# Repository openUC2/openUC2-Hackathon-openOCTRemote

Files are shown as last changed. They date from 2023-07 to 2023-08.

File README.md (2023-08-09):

# Hackathon: openOCT - Full-field Incoherent Interferemeter for better optical sectioning with remote control capabilities

Welcome to the openOCT Hackathon! In this hackathon, we will be addressing the crucial need for an open-source optical coherence tomography system that can help students learning more about setting up a low-coherence interferemoter. To keep the budget low, we aim for a full-field time domain OCT using an SLD (super luminescent diode) - alternatively one could also try an LED to lower the costs even more

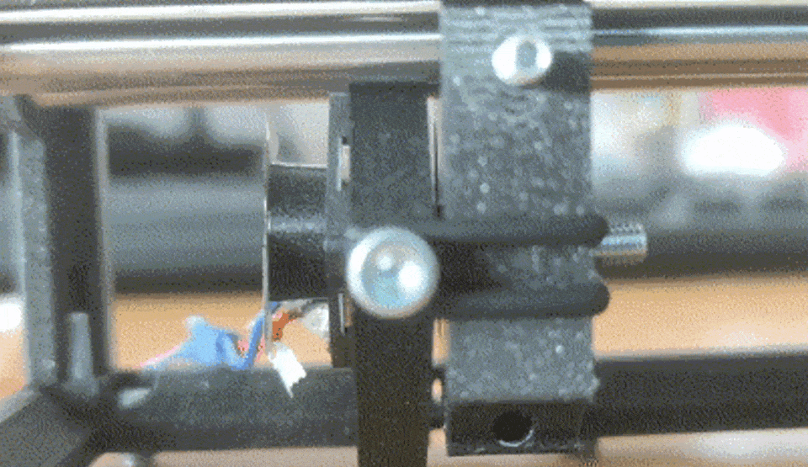
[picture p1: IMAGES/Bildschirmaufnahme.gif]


## Motivation

Optical coherence tomography (OCT) is a non-invasive optical method that allows for deep imaging within tissues. It is primarily based on a Michelson-type interferometer, where the light source is generated by a low-coherence light source, such as a superluminescent diode (SLD). The coherence volume, which represents the volume where constructive interference is observed, is inversely proportional to the spectral bandwidth of the light source.

However, adjusting a Michelson interferometer is not a straightforward process, as the lengths of the reference and sample arms need to match by approximately 10 µm. To address this challenge, a common-path-type full-field OCT is employed, where both arms are illuminated by an SLD, and the sample or mirror is imaged using a long-working distance objective or a simple lens. This alignment method simplifies the process since the "sample" or mirror is brought into focus, ensuring that the path lengths are nearly equal.

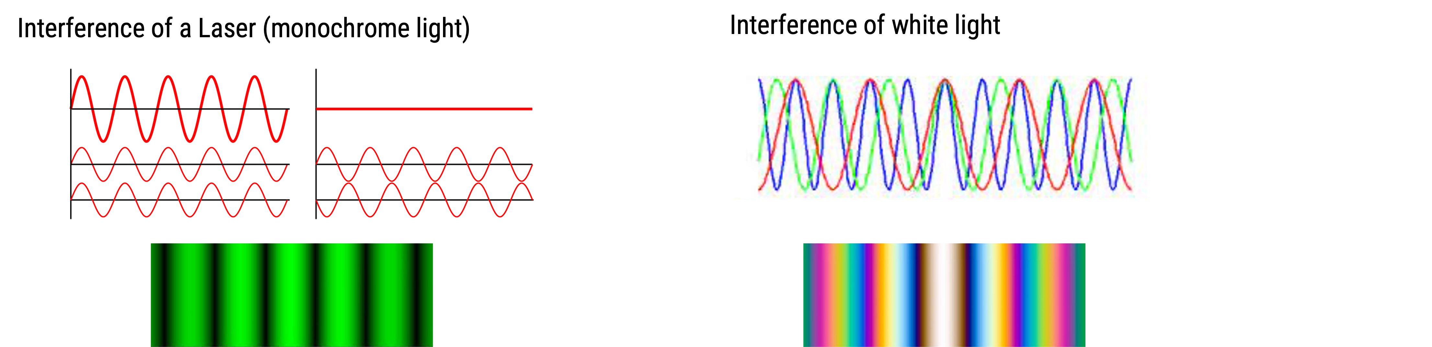
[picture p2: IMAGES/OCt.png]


Such a system enables the estimation of depth in applications like fingertip imaging or visualization of the rods in the retina. Currently available OCT systems are expensive and not accessible to all, and thus there is a need for a more affordable and open system, which our system aims to provide.

In addition to the challenges related to alignment, adjusting such a system becomes even more complex due to the influence of touch, which can change the path lengths. To overcome this, we also intend to automate certain mechanical elements and enable remote access using the TwinLab developed by the Lichtwerkstatt, which provides WebRTC-based access to labware.

For further reading on this topic, please refer to the following sources:
- [Article 1](https://ieeexplore.ieee.org/document/8957575)
- [Article 2](https://pubs.aip.org/aapt/ajp/article-abstract/88/12/1132/859670/Full-field-optical-coherence-tomography-An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)

This will be our main guide star publication:

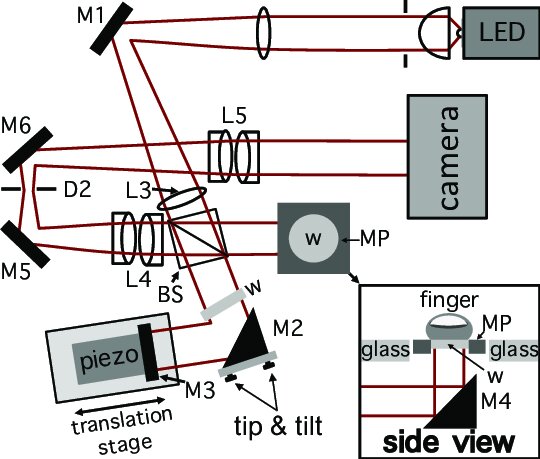
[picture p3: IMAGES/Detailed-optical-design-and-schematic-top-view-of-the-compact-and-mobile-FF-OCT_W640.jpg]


Further reading https://ieeexplore.ieee.org/document/8957575
https://pubs.aip.org/aapt/ajp/article-abstract/88/12/1132/859670/Full-field-optical-coherence-tomography-An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

## Goal

Our primary goal is to set up an optical coherence tomography (OCT) system based on the optical scheme depicted in the diagram. The first step is to ensure that the system is adjusted to observe interference fringes. This involves aligning the components to achieve constructive interference.

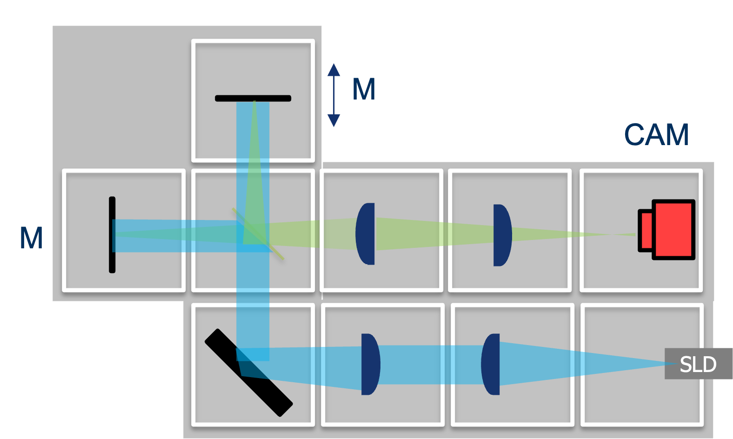
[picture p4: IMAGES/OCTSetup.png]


Once we have successfully obtained interference fringes, our next objective is to acquire a stack of fringes from two mirrors with varying positions. To achieve this, we plan to integrate low-cost stepper motors into one of the mirrors, allowing us to control its movement. The integration of these motors will be done in conjunction with the TwinLab, a versatile platform developed by the Lichtwerkstatt that provides remote access to labware via WebRTC.

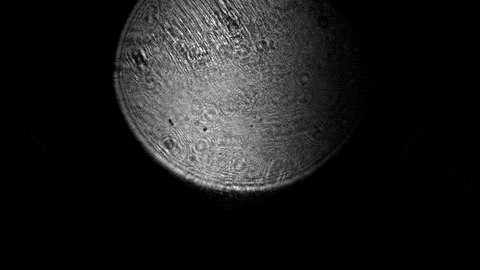
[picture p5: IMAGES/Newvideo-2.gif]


Alternatively, we aim to develop a Jupyter notebook program that integrates the UC2-ESP32/UC2-REST framework with the low-cost stepper motors, enabling automation of the OCT system. This program will facilitate precise control over the motion of the mirrors.

To further enhance the capabilities of our OCT system, we are exploring methods to move the reference mirror along the optical axis. This can be achieved by employing a stepper motor, voice coil motor, or similar mechanism. By varying the position of the reference mirror, we can capture the typical oscillation of the interference over the Z-axis.

In order to process and analyze the acquired data, we plan to develop Python code that can reconstruct the OCT scan. This code will extract the mirror location and reflection information from the data. Additionally, we will investigate techniques to compensate for any potential non-linearity in the motion of the mirrors or stages, ensuring accurate positioning.

Finally, we intend to incorporate a sample, such as layers of coverslips, into the setup and acquire an OCT scan. This will allow us to visualize and analyze the internal structure of the sample using the OCT system.

By accomplishing these goals, we aim to create a functional and cost-effective OCT system that provides valuable imaging capabilities for various applications.

## Background

### Interference

- A phenomenon where two waves interact with each other, resulting in a visible pattern.
- Two wave trains must have a fixed phase relationship to each other.
- Temporal coherence: A light source is split and brought into interference at different times by extending the optical path accordingly.
- Spatial coherence measures the interference capability of two wavelengths from a source originating from different locations.

### OCT

OCT relies on having as small a temporal coherence as possible to increase optical sectioning. This is achieved by using a typical source such as an SLD or LED that has a broad spectrum. Multiple wavelength components interfere simultaneously. Constructive interference of all wavelengths is only visible in a range inversely proportional to the spectrum. The broader the spectrum, the smaller the range where interference can be observed. This makes alignment challenging. Our design overcomes this challenge by ensuring that as soon as we see a sharp image of the reference mirror and the sample on the detector, we are within the same optical path length and thus within the coherence volume.

## Current State: Building the Prototype and Optical Setup

We are currently in the process of building a prototype for the simplified OCT system. The setup eliminates the need for an optical table and instead is mounted on a foam mat, allowing for easier operation and portability.

### TwinLAB Integration

Johannes will tell you more about it. Here you can find some links and thoughts:

https://www.asp.uni-jena.de/digital-teaching/xr-twinlab

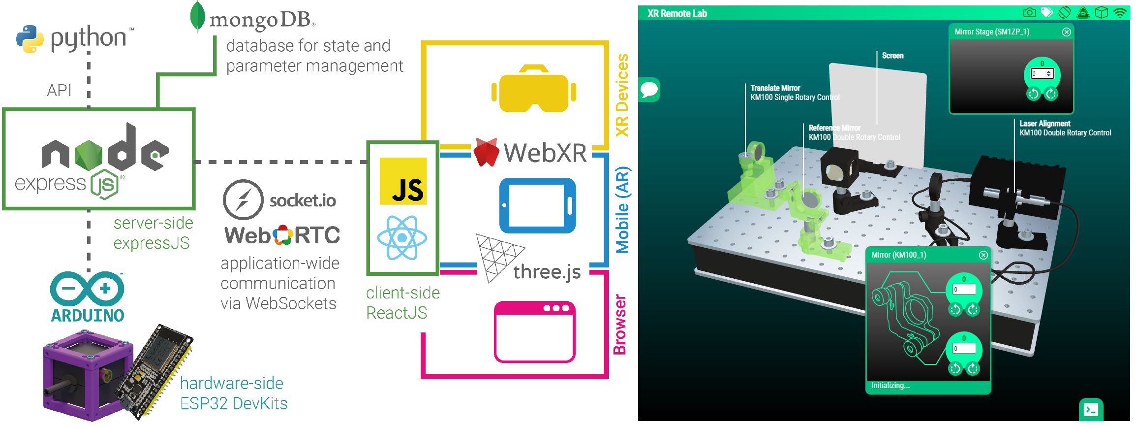
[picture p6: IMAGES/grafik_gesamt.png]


Sources:
https://github.com/Lichtwerkstatt/XRTL_SPA

The idea would be to integrate the UC2 system into this framework

### CAD

The Inventor DEsign Files can be found in the folder [INVENTOR](./INVENTOR)
The STL printing files can be found in the folder [STL](./STL)

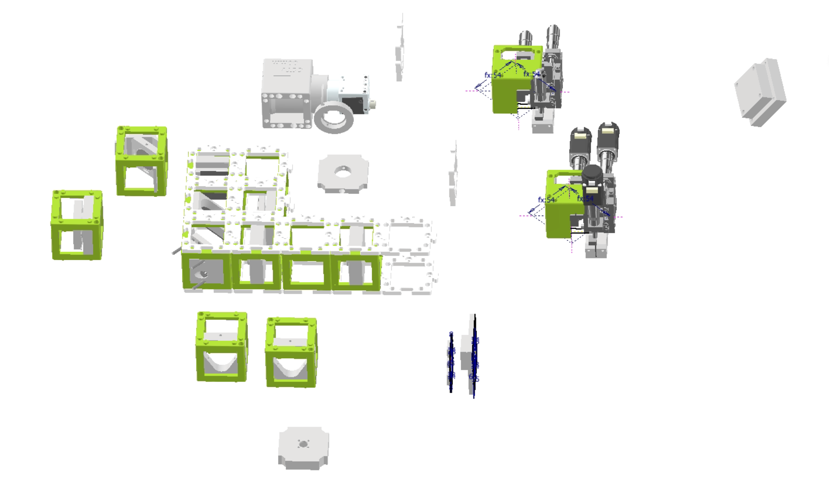
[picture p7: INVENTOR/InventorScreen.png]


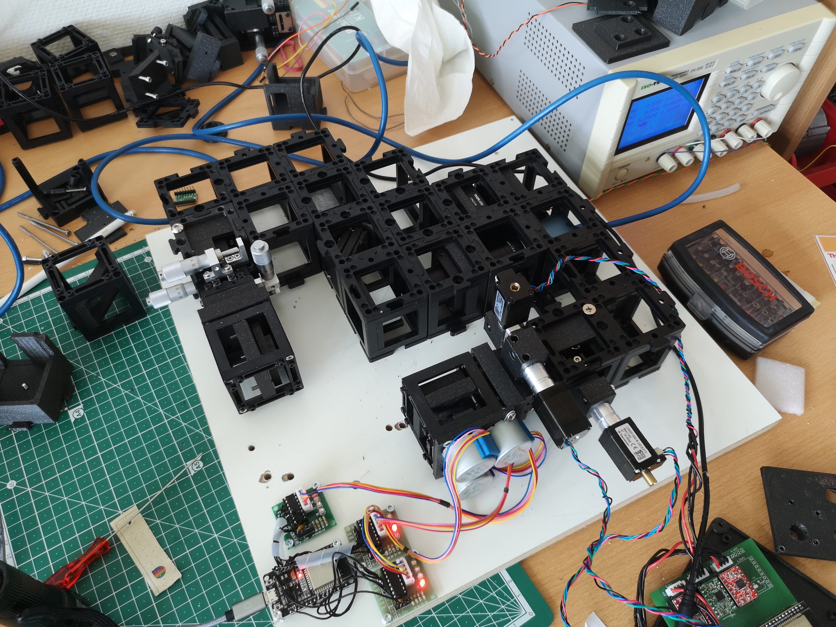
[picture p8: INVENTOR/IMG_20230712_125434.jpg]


### Reference Mirror

The optical setup consists of a minimal number of optical components. The reference mirror (M2) is mounted on a linear stage, enabling forward and backward movement to scan the coherence volume. It is also kinematically held to align the beam with respect to the sample. The entire scanning process will be motorized to minimize vibrations caused by manual movements.

### Light Source

Currently, we are using a Superlum SLD (Superluminescent Diode) as the light source. However, it would be interesting to explore the use of an LED due to their lower cost. For spatial incoherence, a LED with a small emitter could be considered to minimize the visible interference range. The SLD is collimated using lens L1 to illuminate the mirrors and the sample.

### Imaging Optics

The beam splitter cube or the 50% reflective mirror (approximately 1mm thick) divides and recombines the beam paths of the Michelson interferometer before passing through the 100mm objective lens (L2) and the 50mm tube lens, which takes the form of a CCTV lens. The resulting image is captured by a CMOS camera (Deheng IMX 226).

### Sample

In its simplest form, the sample is represented by a mirror mounted on a micrometer XYZ stage, allowing for controlled movement in space. To facilitate interference, it is advisable to kinematically mount the sample as well, ensuring precise alignment and stability during scanning.
### Setting up and Adapting

To disassemble the OPU, you can remove the metal plate at the back and the detection lens using Philips screwdrivers.

The back of the OPU features a complex and precisely adjusted "confocal" microscope:

OPU Lower
*Bottom View*

To attach this unit to a 3D printed assembly, we will enlarge the holes where the lens used to be, making them M3-sized, and then incorporate the assembly into a UC2 insert:

3D Printed Assembly

The Xiao camera module can be adapted using another 3D printed mechanism (customizable to your needs). It's worth noting that the astigmatism is not parallel to the case of the OPU, so it may be necessary to adjust the angle by rotating the camera. Additionally, the focus may be slightly closer than the plastic cap (black) of the camera module allows.

Xiao Camera Module

We create an initial prototype as follows:

Prototype

It is advisable to mount the XIAO camera securely to prevent damage to the flatband cable:

Secure Mounting

The laser diode can be directly powered by the 3V3 supply voltage or controlled using a transistor for on/off switching in the code.

Laser Diode Setup

## Current State: Building the Prototype

We are currently in the advanced stages of constructing the prototype for our simplified OCT system, and several significant milestones have been accomplished:

### Achievements

1. **System Alignment:** We have successfully achieved a satisfactory level of system alignment, ensuring that all the optical components are properly positioned for optimal performance.

2. **Mirror Focusing:** Precise focusing of the mirrors has been achieved, contributing to enhanced imaging quality and accurate interference patterns.

3. **Tip Tilt Optimization:** We have effectively optimized the tip and tilt of the mirrors. This meticulous adjustment has resulted in improved beam steering, critical for obtaining clear interference fringes.

4. **Interference Fringe Generation:** By meticulously aligning the reference mirror and the sample arm, we have managed to generate distinct interference fringes, a pivotal step towards achieving high-resolution OCT imaging.

5. **Motor Control Script:** We have developed a custom script, OCT_motor_movement, which facilitates the control of the motor. Parameters such as speed and the number of steps per second (nSteps) can be adjusted through this script.

6. **Dephasing Control:** The motor movement script allows precise control over dephasing. With a duration of approximately 4 seconds, it covers a range from -nSteps//2 to +nSteps//2, contributing to comprehensive data collection.

7. **Camera Image Acquisition:** We have successfully acquired images using the camera software, Galaxy View. Utilizing the plugin for videos and image saving, we convert the images into TIFF stacks for further processing.

8. **Post-Processing Script:** We have developed the OCT_post_process script, designed to demodulate the stack of acquired images. This script aids in extracting meaningful information from the raw data.

### Upcoming Tasks

1. **Demodulation Testing:** The demodulation script, designed to process the collected data, is poised for testing. Initial results indicate its potential effectiveness, and we are eager to refine it further.

2. **Sample Demodulation Testing:** We intend to initiate testing with a sample, evaluating the demodulation script's performance under practical conditions.

Through these achievements and ongoing efforts, our prototype OCT system is progressing towards its full operational potential, offering simplified setup and enhanced imaging capabilities.

### Code

Luckily we don't need a lot of code. Essentially we will have 3 steppers rotating the thumbscrews of the kinematic mirror mount. Then there is a non-captive stepper motor translating the linear stage.

#### Kinematic mirror mount

These are 28byj-48  stepper motors and will be driven using a ULN2003 board hooked up to our UC2-ESP firmware. The **FIRMWARE**: https://github.com/youseetoo/uc2-esp32/tree/main/main

*Three steppers mounted to the insert*
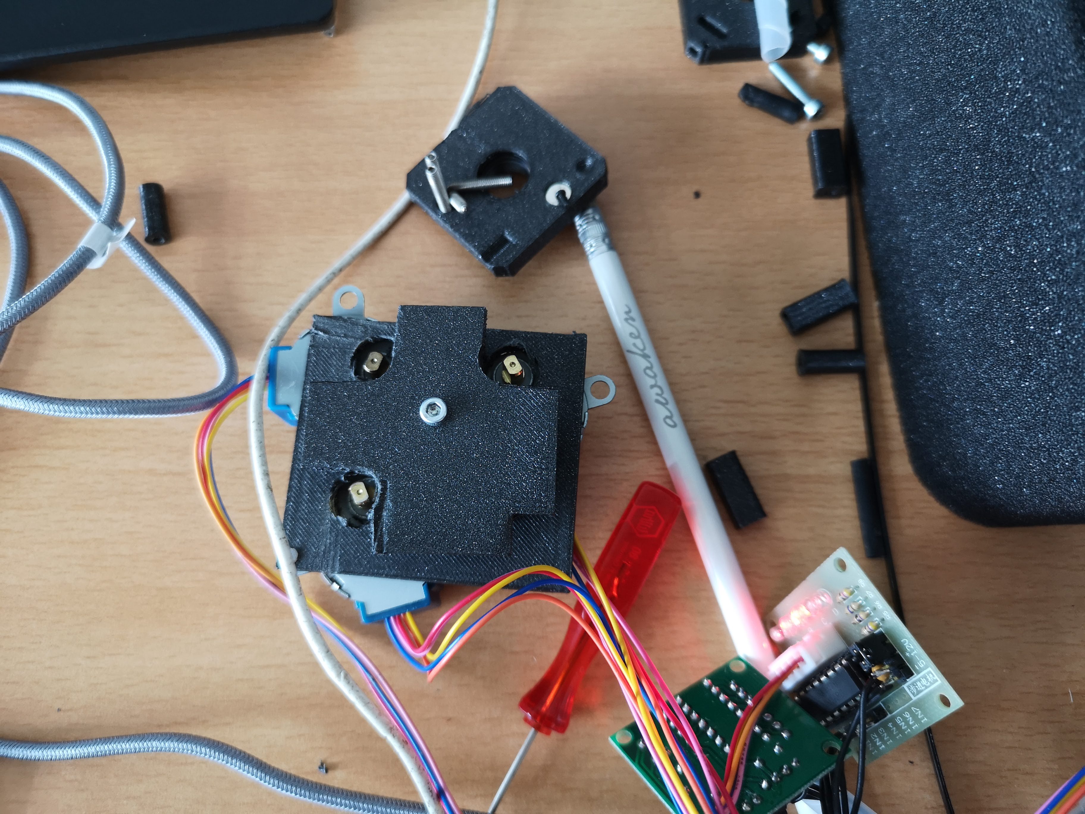
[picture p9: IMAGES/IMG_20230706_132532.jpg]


*All motor drivers hooked up the ESP32 controlled by UC2-ESP*
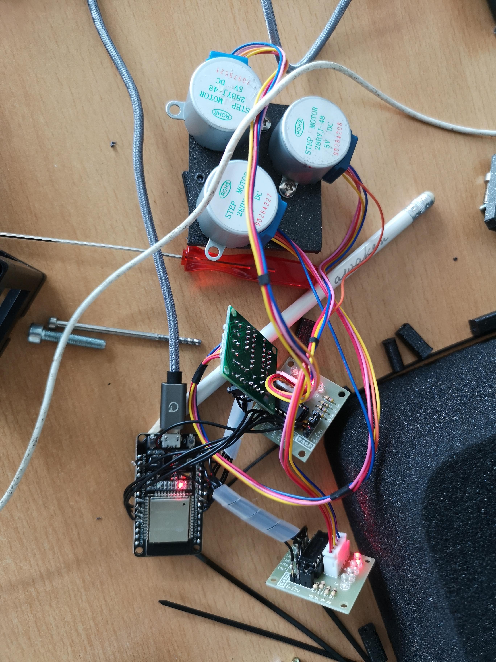
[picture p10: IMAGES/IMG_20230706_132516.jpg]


*Module in Action*
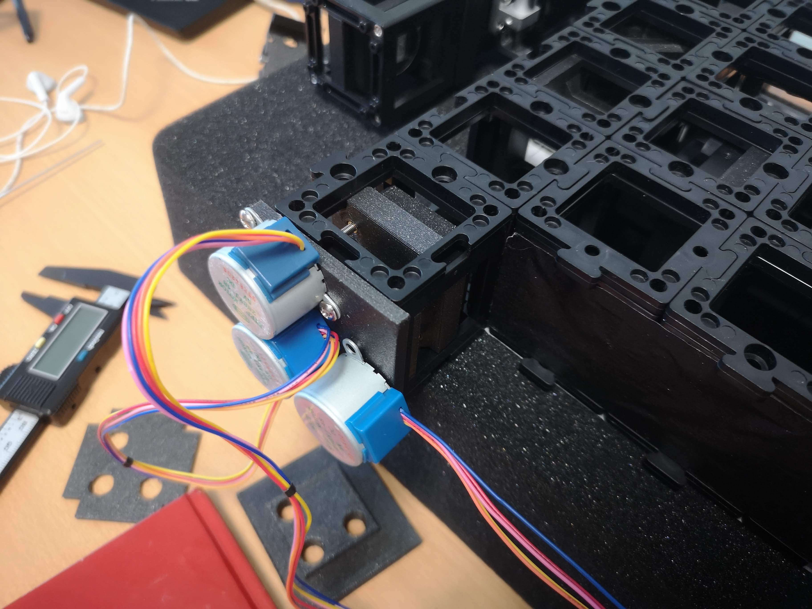
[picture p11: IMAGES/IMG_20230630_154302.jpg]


You can access them using the `Rotataor` class: https://github.com/youseetoo/uc2-esp32/blob/main/main/src/rotator/Rotator.cpp

**The pincofiguration** is determined here:
https://github.com/youseetoo/uc2-esp32/blob/main/main/PinConfig.h#L427
You can download the code, import it into Visual Studio's Platform.io, compile and upload it to the ESP32 board and connect the 3 ULN2003 boards to the following pins:

```cpp
    // ESP32-WEMOS D1 R32
    int ROTATOR_X_0 = GPIO_NUM_13;
    int ROTATOR_X_1 = GPIO_NUM_14;
    int ROTATOR_X_2 = GPIO_NUM_12;
    int ROTATOR_X_3 = GPIO_NUM_27;
    int ROTATOR_Y_0 = GPIO_NUM_26;
    int ROTATOR_Y_1 = GPIO_NUM_33;
    int ROTATOR_Y_2 = GPIO_NUM_25;
    int ROTATOR_Y_3 = GPIO_NUM_32;    
    int ROTATOR_Z_0 = GPIO_NUM_5;
    int ROTATOR_Z_1 = GPIO_NUM_19;
    int ROTATOR_Z_2 = GPIO_NUM_18;
    int ROTATOR_Z_3 = GPIO_NUM_21;  
```

If everything goes right, you can control the motors using our web-gui that is available here: https://youseetoo.github.io/indexWebSerialTest.html

You can control the steppers using the following python code:

In Python code that means (after `pip install UC2-REST`):

```py
import uc2rest
import numpy as np
import time

port = "unknown"

ESP32 = uc2rest.UC2Client(serialport=port, DEBUG=True)
# setting debug output of the serial to true - all message will be printed
ESP32.serial.DEBUG=True

#%%
# test Rotators
ESP32.rotator.move_x(steps=10000, speed=10000, is_blocking=True)
ESP32.rotator.move_y(steps=1000, speed=1000, is_blocking=True, is_enabled=False)
ESP32.rotator.move_z(steps=1000, speed=1000, is_blocking=True)
ESP32.rotator.move_y(steps=1000, speed=1000, is_blocking=True, is_enabled=False)
ESP32.rotator.move_t(steps=1000, speed=1000)
```

#### XYZ Stage

This video should describe some of the details for the stage's operation:



Depending how you will connect the stepper to the ESP you can simply use the flashing tool and upload the latest firmware (https://youseetoo.githu.io)

You can also use the web-tool to move the motor (https://youseetoo.github.io/indexWebSerialTest.html).

In Python code that means (after `pip install UC2-REST`):

```py
import uc2rest
import numpy as np
import time

port = "unknown"

ESP32 = uc2rest.UC2Client(serialport=port, DEBUG=True)
# setting debug output of the serial to true - all message will be printed
ESP32.serial.DEBUG=True

#%%
# test motor
ESP32.motor.move_x(steps=10000, speed=10000, is_blocking=True)
ESP32.motor.move_y(steps=1000, speed=1000, is_blocking=True, is_enabled=False)
ESP32.motor.move_z(steps=1000, speed=1000, is_blocking=True)
```

#### Camera

We use a Daheng camera. For this we would need to download the drivers:
https://dahengimaging.com/downloads/Galaxy_Windows_EN_32bits%2064bits_1.23.2305.9161.zip

After installation, you will have access to the Galaxy Viewer to get the image stream.

We can also read out frames in Python. For this we have the option to use the camera in ImSwitch. Alternatively, you can simply use the UC2-REST library shown above and some simple python lines (see also [the python SDK](Python SDK))

```py
# version:1.0.1905.9051
import gxipy as gx
from PIL import Image

def main():
    # print the demo information
    print("")
    print("-------------------------------------------------------------")
    print("Sample to show how to acquire mono image continuously and show acquired image.")
    print("-------------------------------------------------------------")
    print("")
    print("Initializing......")
    print("")

    # create a device manager
    device_manager = gx.DeviceManager()
    dev_num, dev_info_list = device_manager.update_device_list()
    if dev_num is 0:
        print("Number of enumerated devices is 0")
        return

    # open the first device
    cam = device_manager.open_device_by_index(1)

    # exit when the camera is a color camera
    if cam.PixelColorFilter.is_implemented() is True:
        print("This sample does not support color camera.")
        cam.close_device()
        return

    # set continuous acquisition
    cam.TriggerMode.set(gx.GxSwitchEntry.OFF)

    # set exposure
    cam.ExposureTime.set(10000)

    # set gain
    cam.Gain.set(10.0)

    # start data acquisition
    cam.stream_on()

    # acquire image: num is the image number
    num = 1
    for i in range(num):
        # get raw image
        raw_image = cam.data_stream[0].get_image()
        if raw_image is None:
            print("Getting image failed.")
            continue

        # create numpy array with data from raw image
        numpy_image = raw_image.get_numpy_array()
        if numpy_image is None:
            continue

        # show acquired image
        img = Image.fromarray(numpy_image, 'L')
        img.show()

        # print height, width, and frame ID of the acquisition image
        print("Frame ID: %d   Height: %d   Width: %d"
              % (raw_image.get_frame_id(), raw_image.get_height(), raw_image.get_width()))

    # stop data acquisition
    cam.stream_off()

    # close device
    cam.close_device()

if __name__ == "__main__":
    main()

```

#### Image Processing

Ultimatively, the goal is to capture a stack of images while the refernce arm is moving alon ghte optical path difference. Then image processing will help you to recover the reflection map of your sample.

## Safety

**LASER Safety/Radition** Never watch into the source directly. You may hurt your eye. Always be careful!

**Risk of Squeezing fingers** Don't hurt your fingers!

## When Goal is met?

- Control the setup using your computer
- Think about an integration into the TWINLab https://www.asp.uni-jena.de/digital-teaching/xr-twinlab
- get interference fringes
- align the system to get an OCT signal
- acquire a image stack and process it

## Ressources
- https://hackaday.com/2021/02/02/dvd-optics-power-this-scanning-laser-microscope/

## Future and outlook

In conclusion, the development of the "common-path" OCT prototype has marked a significant step forward, though it has also revealed critical areas for improvement. The initial design, hindered by a vulnerability to vibrations due to the lengthy reference and sample arms and the tuning fork-like mounting of mirrors and samples, needed rethinking. The recommendation to miniaturize the setup into a single cube, eliminating potential sources of reduced mechanical stiffness, has proven to be a wise direction.

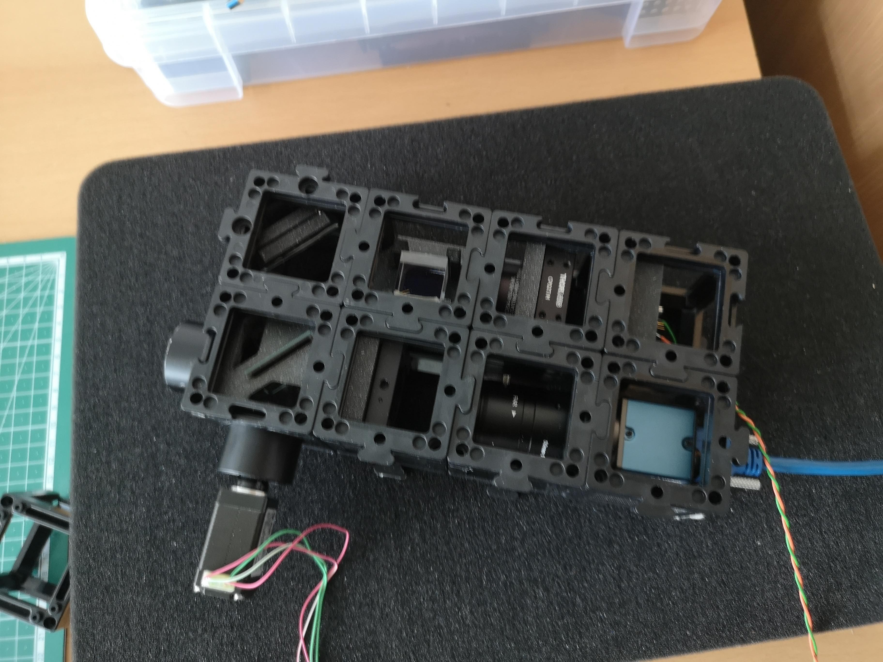
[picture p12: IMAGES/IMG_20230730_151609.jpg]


The innovative one-cube design, featuring a reference arm with z-only positioning and kinematically mounted other arm, cleverly couples a non-captive motor with a TMC stepper motor. This approach has helped to overcome the vibrational challenges associated with previous A4988 stepper drivers. Although the mounting of real samples remains an open question and subject for future experimentation, the current setup is undoubtedly more stable and more straightforward to realize.

The openOCT project's future looks promising, with a newfound focus on robustness and precision. By continuing to address the challenges identified and adapting the prototype accordingly, there is immense potential for achieving a state-of-the-art system that could redefine OCT technology. The pathway towards miniaturization and stability has already begun to be paved, opening exciting possibilities for research and applications.
In the future we definitely want to replace the SLD with an LED due to supply chain issues

### Results

First results on in-cube OCT with the TMC motor controller and the Superlum SLD:

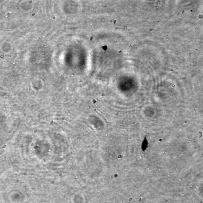
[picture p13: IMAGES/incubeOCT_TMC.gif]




## Results

Raw-data can be found here:
10.5281/zenodo.8196533

```python
import numpy as np
import matplotlib.pyplot as plt
```

```python
from skimage import io
im = io.imread('stack140.tif')
```

```python
plt.imshow(im[20,:,:])
```

    <matplotlib.image.AxesImage at 0x22e77248848>

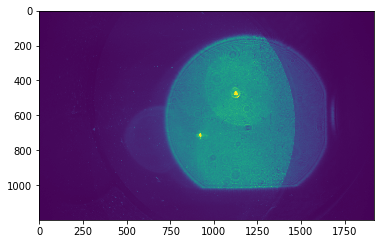
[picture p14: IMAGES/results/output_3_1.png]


```python
im_cut=im[:,120:1050,700:1500]
```

```python
plt.plot(im_cut[:,300,700])
```

    [<matplotlib.lines.Line2D at 0x22e774f3608>]

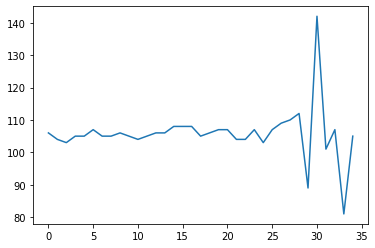
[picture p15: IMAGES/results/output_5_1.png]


```python
ans=[]
stack0=im_cut[:,300,500]*1.0
for i in range(0,stack0.shape[0]-5):
    valTemp=np.power(stack0[i+1]-stack0[i+3],2)-np.multiply((stack0[i]-stack0[i+2]),(stack0[i+2]-stack0[i+4]))
    ans.append(valTemp)
```

```python
plt.plot(ans)
```

    [<matplotlib.lines.Line2D at 0x22e770c1b88>]

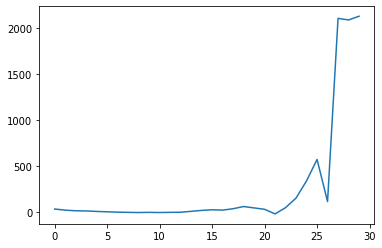
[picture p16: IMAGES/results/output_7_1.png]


```python
plt.imshow(im_cut[31,:,:])
```

    <matplotlib.image.AxesImage at 0x22e77564fc8>

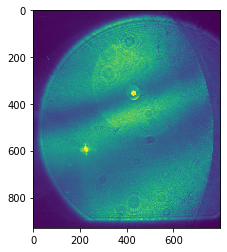
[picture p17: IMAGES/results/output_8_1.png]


```python
size = im_cut.shape
im_stack=im_cut.reshape((size[0],size[1]*size[2]))

```

```python
size
```

    (35, 930, 800)

```python
plt.plot(im_stack[2,:])
```

    [<matplotlib.lines.Line2D at 0x22e7717de08>]

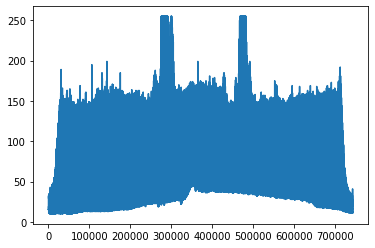
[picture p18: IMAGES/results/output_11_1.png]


```python
stack0 = im_stack
```

```python
im_ft = np.fft.fft(im_cut,None,0)
```

```python
plt.imshow(np.abs(im_ft[17,:,:]))
```

    <matplotlib.image.AxesImage at 0x22e8908c248>

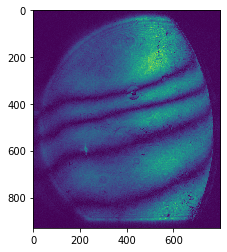
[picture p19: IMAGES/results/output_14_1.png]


```python
ans=[]
stack0=im_cut[:,:,:]*1.0
for i in range(0,size[0]-5):
# i = 0
    valTemp=np.power(stack0[i+1,:]-stack0[i+3,:],2)-np.multiply((stack0[i,:]-stack0[i+2,:]),(stack0[i+2,:]-stack0[i+4,:]))
    ans.append(valTemp)
    #print(pixel[i+2])
# print('Distance:')
#print(q)

```

```python
ans=[]
stack0=im_cut[:,:,:]*1.0
for i in range(0,size[0]-5):
# i = 0
    valTemp=np.power(stack0[i+1,:]-stack0[i+3,:],2)-np.power((stack0[i,:]-stack0[i+2,:]),2)
    ans.append(valTemp)
    #print(pixel[i+2])
# print('Distance:')
#print(q)
```

```python
stack0.shape
```

    (35, 930, 800)

```python
out = np.vstack(ans)
size2=out.shape
size2[0]
```

    27900

```python
out.shape
out2 = out.reshape((35-5,930,800))
plt.imshow(out2[0,:,:])
```

    <matplotlib.image.AxesImage at 0x22e771e9f88>

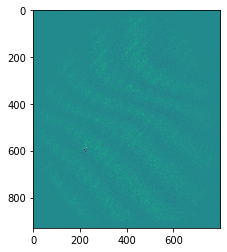
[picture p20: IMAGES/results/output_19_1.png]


```python
out.shape
```

    (27900, 800)

```python
for q in range (1,37):
    pixel2=pixel0[::q]

    #plt.plot(pixel2)

    ans=[]
    pixel=pixel2*1.0
    for i in range(1,len(pixel)-5):
        valTemp=np.power(pixel[i+2]-pixel[i+4],2)-np.multiply((pixel[i-1]-pixel[i+3]),(pixel[i+3]-pixel[i+5]))
        ans.append(valTemp)
        #print(pixel[i+2])
    print('Distance:')
    print(q)
    plt.figure()
    plt.plot(ans)
    plt.show()
```

```python
stack0.shape
```

    (660, 40000)

```python
pixel0=im[:,553,933]
#
print(pixel0.shape)
plt.plot(pixel0)
```

    (660,)

    [<matplotlib.lines.Line2D at 0x2ac8a71f7c8>]

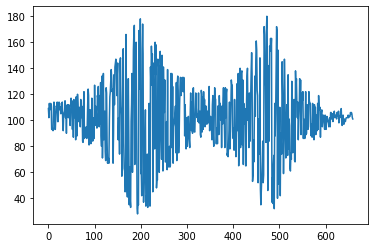
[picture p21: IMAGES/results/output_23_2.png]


```python

for q in range (1,37):
    pixel2=pixel0[::q]

    #plt.plot(pixel2)

    ans=[]
    pixel=pixel2*1.0
    for i in range(1,len(pixel)-5):
        valTemp=np.power(pixel[i+2]-pixel[i+4],2)-np.multiply((pixel[i-1]-pixel[i+3]),(pixel[i+3]-pixel[i+5]))
        ans.append(valTemp)
        #print(pixel[i+2])
    print('Distance:')
    print(q)
    plt.figure()
    plt.plot(ans)
    plt.show()
```

    Distance:
    1

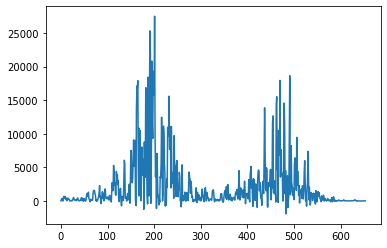
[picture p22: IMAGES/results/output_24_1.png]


    Distance:
    2

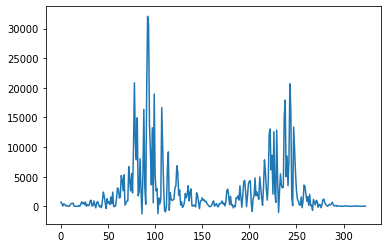
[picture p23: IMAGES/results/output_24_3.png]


    Distance:
    3

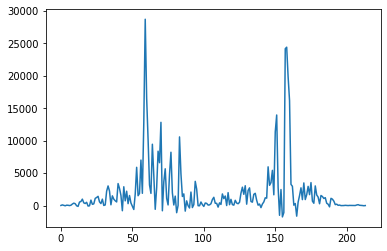
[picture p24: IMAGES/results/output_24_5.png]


    Distance:
    4

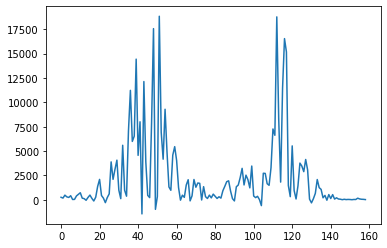
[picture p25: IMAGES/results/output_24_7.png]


    Distance:
    5

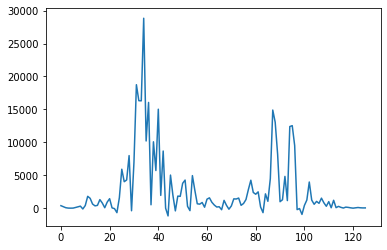
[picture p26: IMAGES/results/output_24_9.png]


    Distance:
    6

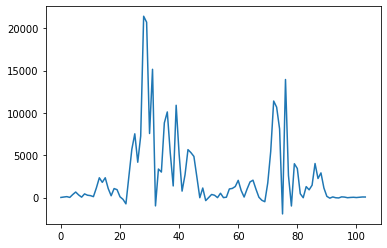
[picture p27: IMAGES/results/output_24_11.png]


    Distance:
    7

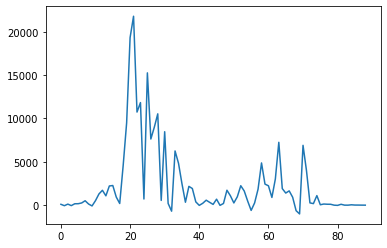
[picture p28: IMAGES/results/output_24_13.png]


    Distance:
    8

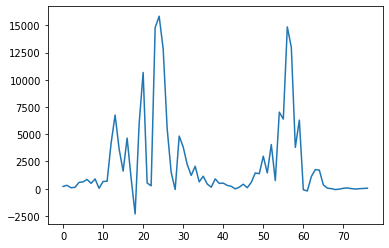
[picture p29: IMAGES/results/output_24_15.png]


    Distance:
    9

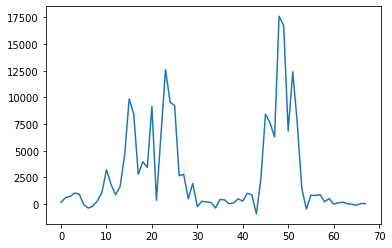
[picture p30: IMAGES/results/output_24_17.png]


    Distance:
    10

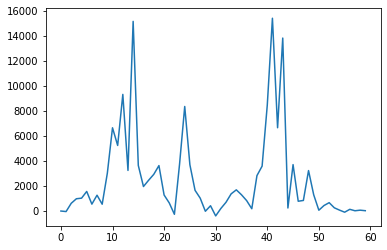
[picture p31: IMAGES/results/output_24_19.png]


    Distance:
    11

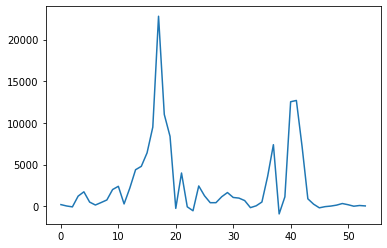
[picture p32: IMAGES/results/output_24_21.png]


    Distance:
    12

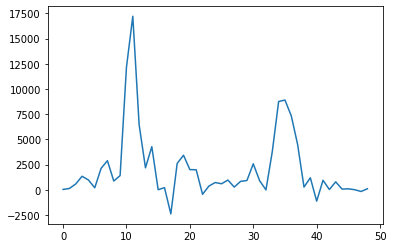
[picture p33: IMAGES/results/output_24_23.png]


    Distance:
    13

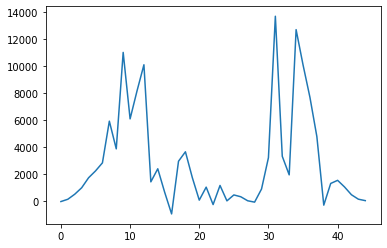
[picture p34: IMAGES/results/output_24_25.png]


    Distance:
    14

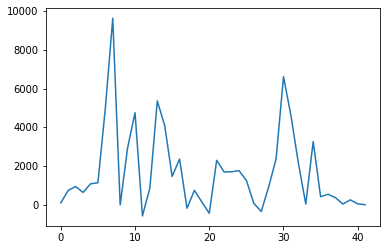
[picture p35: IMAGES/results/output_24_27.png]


    Distance:
    15

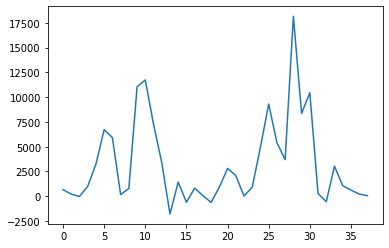
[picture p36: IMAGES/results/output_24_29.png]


    Distance:
    16

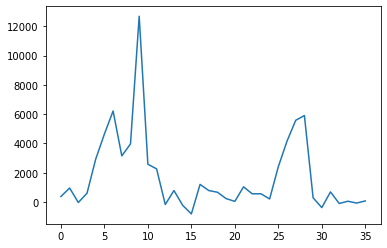
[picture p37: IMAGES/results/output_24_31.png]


    Distance:
    17

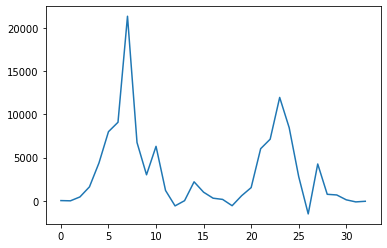
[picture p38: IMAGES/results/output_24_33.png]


    Distance:
    18

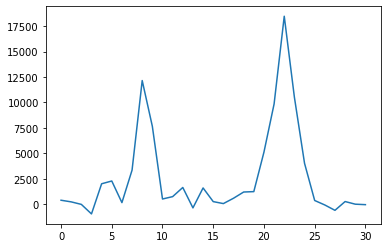
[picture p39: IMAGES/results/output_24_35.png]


    Distance:
    19

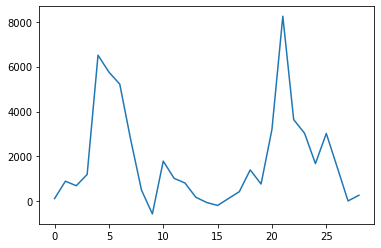
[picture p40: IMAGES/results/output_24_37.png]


    Distance:
    20

png

    Distance:
    21

png

    Distance:
    22

png

    Distance:
    23

png

    Distance:
    24

png

    Distance:
    25

png

    Distance:
    26

png

    Distance:
    27

png

    Distance:
    28

png

    Distance:
    29

png

    Distance:
    30

png

    Distance:
    31

png

    Distance:
    32

png

    Distance:
    33

png

    Distance:
    34

png

    Distance:
    35

png

    Distance:
    36

png

```python
plt.plot(pixel2)
```

    [<matplotlib.lines.Line2D at 0x2ac52d46648>]

png

```python
ans=[]
pixel=pixel2*1.0
for i in range(1,len(pixel)-5):
    valTemp=np.power(pixel[i+2]-pixel[i+4],2)-np.multiply((pixel[i-1]-pixel[i+3]),(pixel[i+3]-pixel[i+5]))
    ans.append(valTemp)
    #print(pixel[i+2])

plt.plot(ans)
```

    [<matplotlib.lines.Line2D at 0x2ac52e1bf48>]

png

```python

```

    [<matplotlib.lines.Line2D at 0x2ac52c12388>]

png

```python
import os
os.getcwd()
```

    'C:\\ProgramData\\Galaxy\\userdata\\ImagesAndVideos\\hackaday\\MER2-230-168U3M(FDG22050153)'

## License

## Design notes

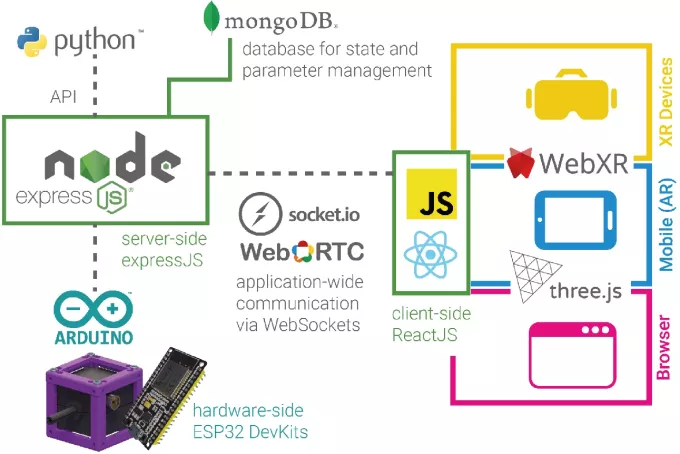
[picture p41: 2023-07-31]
IMAGES/ASP_digiphoton_XRTwinLab_overview.webp

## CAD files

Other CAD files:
INVENTOR/00_Astromedia_FronSurfaceMirror_40x30mmx1mm.ipt
INVENTOR/00_Basler_ace_USB3_C-Mount.ipt
INVENTOR/00_Berrybase_CCTVLens_100mm.ipt
INVENTOR/00_CMountSpacer_CCTVLens_Daheng.ipt
INVENTOR/00_Joy-IT-B20SHD4353_NEMA8_captive.ipt
INVENTOR/00_Lens_neg_50mm_India.ipt
INVENTOR/00_NeoDymMagnet_8x3mm.ipt
INVENTOR/00_Screw_Ball_Spring_Head_M3x30mm.ipt
INVENTOR/00_Thorlabs_PF10-03-P01-Step.ipt
INVENTOR/00_Threaded_Screw_Insert_M3.ipt
INVENTOR/00_XYZstage_micro_LT-4047-S1.ipt
INVENTOR/10_Base_puzzle_v3.ipt
INVENTOR/10_Cube_1x1_IM.ipt
INVENTOR/11_Cube_Berrybase_CCTV_100mm_Lens_Cube_half.ipt
INVENTOR/20_Cube_Insert_Kinematic_Astromedia_30x40x1_45_pro_magnetic.ipt
INVENTOR/20_Cube_Insert_Kinematic_KES400AMount_90_pro_v3.ipt
INVENTOR/20_Cube_Insert_Kinematic_Mirror_45_pro_magnetic.ipt
INVENTOR/20_Cube_Insert_Kinematic_Mirror_45_pro_v3.ipt
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

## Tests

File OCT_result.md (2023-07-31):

```python
import numpy as np
import matplotlib.pyplot as plt
```

    ---------------------------------------------------------------------------

    ModuleNotFoundError                       Traceback (most recent call last)

    <ipython-input-209-bd177e4be8d7> in <module>
          1 import numpy as np
          2 import matplotlib.pyplot as plt
    ----> 3 import napari

    ModuleNotFoundError: No module named 'napari'

```python
import napari
```

    ---------------------------------------------------------------------------

    ModuleNotFoundError                       Traceback (most recent call last)

    <ipython-input-211-1e1049a33073> in <module>
    ----> 1 import napari

    ModuleNotFoundError: No module named 'napari'

```python
from skimage import io
im = io.imread('stack140.tif')
```

```python
plt.imshow(im[20,:,:])
```

    <matplotlib.image.AxesImage at 0x22e77248848>

png

```python
im_cut=im[:,120:1050,700:1500]
```

```python
plt.plot(im_cut[:,300,700])
```

    [<matplotlib.lines.Line2D at 0x22e774f3608>]

png

```python
ans=[]
stack0=im_cut[:,300,500]*1.0
for i in range(0,stack0.shape[0]-5):
    valTemp=np.power(stack0[i+1]-stack0[i+3],2)-np.multiply((stack0[i]-stack0[i+2]),(stack0[i+2]-stack0[i+4]))
    ans.append(valTemp)
```

```python
plt.plot(ans)
```

    [<matplotlib.lines.Line2D at 0x22e770c1b88>]

png

```python
plt.imshow(im_cut[31,:,:])
```

    <matplotlib.image.AxesImage at 0x22e77564fc8>

png

```python
size = im_cut.shape
im_stack=im_cut.reshape((size[0],size[1]*size[2]))

```

```python
size
```

    (35, 930, 800)

```python
plt.plot(im_stack[2,:])
```

    [<matplotlib.lines.Line2D at 0x22e7717de08>]

png

```python
stack0 = im_stack
```

```python
im_ft = np.fft.fft(im_cut,None,0)
```

```python
plt.imshow(np.abs(im_ft[17,:,:]))
```

    <matplotlib.image.AxesImage at 0x22e8908c248>

png

```python
ans=[]
stack0=im_cut[:,:,:]*1.0
for i in range(0,size[0]-5):
# i = 0
    valTemp=np.power(stack0[i+1,:]-stack0[i+3,:],2)-np.multiply((stack0[i,:]-stack0[i+2,:]),(stack0[i+2,:]-stack0[i+4,:]))
    ans.append(valTemp)
    #print(pixel[i+2])
# print('Distance:')
#print(q)

```

```python
ans=[]
stack0=im_cut[:,:,:]*1.0
for i in range(0,size[0]-5):
# i = 0
    valTemp=np.power(stack0[i+1,:]-stack0[i+3,:],2)-np.power((stack0[i,:]-stack0[i+2,:]),2)
    ans.append(valTemp)
    #print(pixel[i+2])
# print('Distance:')
#print(q)
```

```python
stack0.shape
```

    (35, 930, 800)

```python
out = np.vstack(ans)
size2=out.shape
size2[0]
```

    27900

```python
out.shape
out2 = out.reshape((35-5,930,800))
plt.imshow(out2[0,:,:])
```

    <matplotlib.image.AxesImage at 0x22e771e9f88>

png

```python
out.shape
```

    (27900, 800)

```python
for q in range (1,37):
    pixel2=pixel0[::q]

    #plt.plot(pixel2)

    ans=[]
    pixel=pixel2*1.0
    for i in range(1,len(pixel)-5):
        valTemp=np.power(pixel[i+2]-pixel[i+4],2)-np.multiply((pixel[i-1]-pixel[i+3]),(pixel[i+3]-pixel[i+5]))
        ans.append(valTemp)
        #print(pixel[i+2])
    print('Distance:')
    print(q)
    plt.figure()
    plt.plot(ans)
    plt.show()
```

```python
stack0.shape
```

    (660, 40000)

```python
pixel0=im[:,553,933]
#
print(pixel0.shape)
plt.plot(pixel0)
```

    (660,)

    [<matplotlib.lines.Line2D at 0x2ac8a71f7c8>]

png

```python

for q in range (1,37):
    pixel2=pixel0[::q]

    #plt.plot(pixel2)

    ans=[]
    pixel=pixel2*1.0
    for i in range(1,len(pixel)-5):
        valTemp=np.power(pixel[i+2]-pixel[i+4],2)-np.multiply((pixel[i-1]-pixel[i+3]),(pixel[i+3]-pixel[i+5]))
        ans.append(valTemp)
        #print(pixel[i+2])
    print('Distance:')
    print(q)
    plt.figure()
    plt.plot(ans)
    plt.show()
```

    Distance:
    1

png

    Distance:
    2

png

    Distance:
    3

png

    Distance:
    4

png

    Distance:
    5

png

    Distance:
    6

png

    Distance:
    7

png

    Distance:
    8

png

    Distance:
    9

png

    Distance:
    10

png

    Distance:
    11

png

    Distance:
    12

png

    Distance:
    13

png

    Distance:
    14

png

    Distance:
    15

png

    Distance:
    16

png

    Distance:
    17

png

    Distance:
    18

png

    Distance:
    19

png

    Distance:
    20

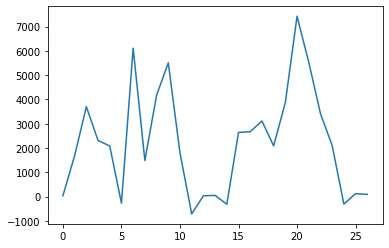
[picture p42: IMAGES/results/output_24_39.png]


    Distance:
    21

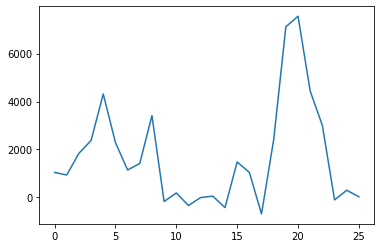
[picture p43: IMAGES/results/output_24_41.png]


    Distance:
    22

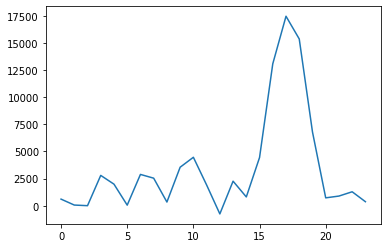
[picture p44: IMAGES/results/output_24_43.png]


    Distance:
    23

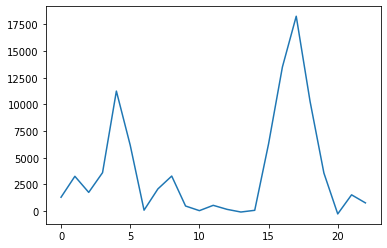
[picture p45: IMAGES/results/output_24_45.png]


    Distance:
    24

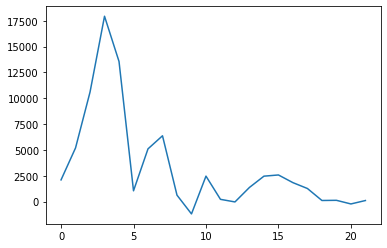
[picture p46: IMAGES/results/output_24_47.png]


    Distance:
    25

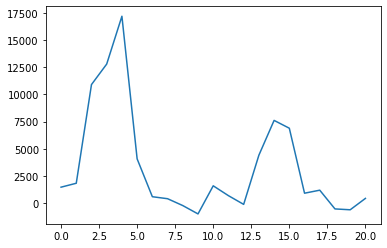
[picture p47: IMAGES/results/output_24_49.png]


    Distance:
    26

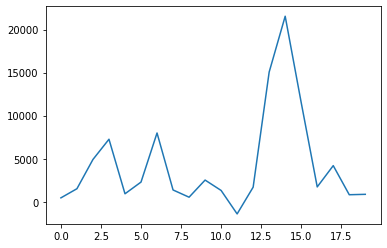
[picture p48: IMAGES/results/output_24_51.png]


    Distance:
    27

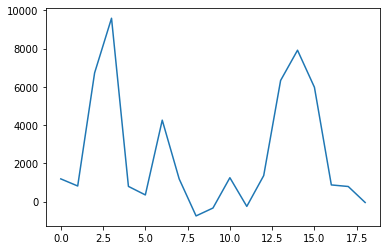
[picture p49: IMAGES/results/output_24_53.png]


    Distance:
    28

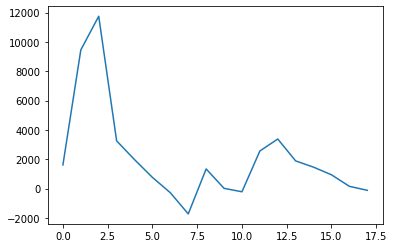
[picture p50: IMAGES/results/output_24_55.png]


    Distance:
    29

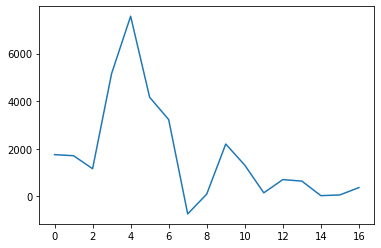
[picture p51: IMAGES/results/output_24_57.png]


    Distance:
    30

png

    Distance:
    31

png

    Distance:
    32

png

    Distance:
    33

png

    Distance:
    34

png

    Distance:
    35

png

    Distance:
    36

png

```python
plt.plot(pixel2)
```

    [<matplotlib.lines.Line2D at 0x2ac52d46648>]

png

```python
ans=[]
pixel=pixel2*1.0
for i in range(1,len(pixel)-5):
    valTemp=np.power(pixel[i+2]-pixel[i+4],2)-np.multiply((pixel[i-1]-pixel[i+3]),(pixel[i+3]-pixel[i+5]))
    ans.append(valTemp)
    #print(pixel[i+2])

plt.plot(ans)
```

    [<matplotlib.lines.Line2D at 0x2ac52e1bf48>]

png

```python

```

    [<matplotlib.lines.Line2D at 0x2ac52c12388>]

png

```python
import os
os.getcwd()
```

    'C:\\ProgramData\\Galaxy\\userdata\\ImagesAndVideos\\hackaday\\MER2-230-168U3M(FDG22050153)'

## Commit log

2023-07-11 Adding Inventor Designfiles
    [00_Astromedia_FronSurfaceMirror_40x30mmx1mm.ipt, 00_Basler_ace_USB3_C-Mount.ipt, 00_Berrybase_CCTVLens_100mm.ipt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]
2023-07-11 added elements for motorize the adjustment of the x,y,z mirrors (reference and sample)
    [Application_Hackathon_openOCT.0006.iam, Application_Hackathon_openOCT.iam, Assembly_XYZ_Stage_Micrometer_lightsheet.0003.iam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]
2023-07-12 Refining modules for openOCT
    [Application_Hackathon_openOCT.0006.iam, Application_Hackathon_openOCT.iam, Assembly_Cube_Kinematic_Mirrormount_Thorlabs_45_PRO_v3.0016.iam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]
2023-07-30 adding results
    [Application_Hackathon_openOCT.0008.iam]
